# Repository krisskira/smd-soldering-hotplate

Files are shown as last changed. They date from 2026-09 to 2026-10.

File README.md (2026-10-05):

<a href="https://krisskira.github.io/smd-soldering-hotplate/">
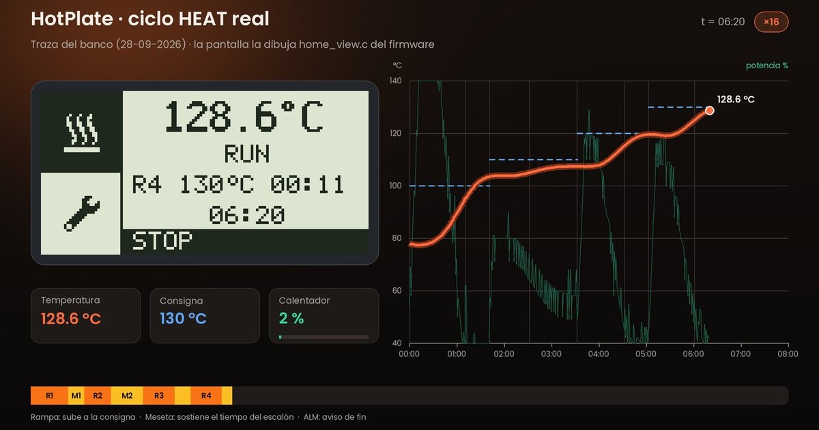
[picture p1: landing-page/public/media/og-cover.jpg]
HotPlate: a real HEAT cycle, with HotPanel and the temperature curve
  
</a>

# HotPlate

An open SMD reflow station. Instead of heating by eye, it runs a **Soldering Profile**: a precise temperature curve, step by step. It ramps under control, holds each plateau for the right time, signals when it is done and cools down on its own.

[Site](https://krisskira.github.io/smd-soldering-hotplate/) · [HotPanel and Studio](#two-ways-to-run-it) · [Docs](docs/README.md) · [Email](mailto:krisskira@gmail.com) · [Leer en español](README.es.md)

## What it does

- **HEAT** runs the whole profile from one gesture: optional wait, preheat, up to four rising or flat steps, then cooldown.
- **Scheduled start** waits from 00:00 (immediate) up to 12:00 before the cycle begins.
- **Predictive PI** cuts power before the target, so the plate's own inertia does not overshoot.
- **Autotune**, launched from HotPlate Studio, learns how the plate responds and stores the gains.
- **Safety** keeps the heater off at boot. A sensor fault or a reading above `temp_max_c` cuts the output at once.

## Two ways to run it

- **HotPanel**, the onboard interface: a large temperature, two tiles and a knob. Turn to choose, press to confirm. Heat starts or stops the cycle. Settings edits the four steps and the wait clock.
- **HotPlate Studio**, the desktop app over USB: live temperature chart, profile editing, CSV export, autotune and the limits the panel does not expose. When Studio takes control, HotPanel shows **USB** and local input locks. The two modes never run together.

## What's in the repo

- [`firmware/avr/`](firmware/avr/) — ATmega16 firmware at 8 MHz. The map of docs and code starts at [product features](firmware/avr/doc/product_features.md), [program flows](firmware/avr/doc/program_flows.md) and [architecture](firmware/avr/doc/architecture.md).
- [`hotplate-studio/`](hotplate-studio/) — HotPlate Studio (Python). The screens it follows are in [`hotplate-studio/design/`](hotplate-studio/design/).
- [`hardware/`](hardware/) — KiCad board and datasheets.
- [`mechanical/`](mechanical/) — 3D enclosure, covers and knob.
- [`landing-page/`](landing-page/) — the public site, React and TypeScript on Vite.

Flash is 16 KB. Thermal control, safety and the approved UI come first. See the [feature budget](firmware/avr/doc/feature_budget.md).

## Build

```bash
cd firmware/avr && make clean && make && make size && make usb-host-test

cd hotplate-studio && pip install -r requirements.txt && python app.py

cd landing-page && npm install && npm run dev
```

The site publishes to GitHub Pages from `.github/workflows/pages.yml` on every push to `main` that touches `landing-page/`. In the repository: **Settings → Pages → Source: GitHub Actions**.

## License

Open hardware and software. Use, study, modify and share it at your own risk. It works with mains power and high temperatures.

| What | License |
|---|---|
| Firmware and HotPlate Studio | [MIT](LICENSE) |
| Board and 3D models | [CERN-OHL-P-2.0](LICENSE) |
| Docs and icons | [CC BY 4.0](LICENSE) |

The full text is in [LICENSE](LICENSE).

Author: **Crhistian David Vergara Gómez** · **krisskira@gmail.com**

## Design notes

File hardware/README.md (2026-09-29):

# Hardware

## PCB (`pcb/`)

Proyecto KiCad de **HotPlate**:

- `controller.*` — placa de control (ATmega16, LCD, encoder, MAX31865, …)
- `power-stage.*` — etapa de potencia / SSR
- `smd-soldering-hotplate-pcb.csv` — BOM
- `pcb-cnc/` — exports CNC si aplica

Abrir los `.kicad_pro` con KiCad 8+.

## Datasheets (`datasheets/`)

PDFs de referencia: ATmega16, MAX31865, MOC3021, BT136, ST7920, CH340, HLK-PM01, etc.

Pines de firmware: `firmware/avr/doc/atmega16_pin_definition_hotplate.md` ↔ `firmware/avr/config/board_pins.h`.

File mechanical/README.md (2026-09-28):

# Mecánica / carcasa 3D

Modelos de carcasa, tapas y perilla (Fusion 360 / 3MF para impresión).

| Archivo | Notas |
|---|---|
| `Case.3mf` / `SolderingHotPlateCase.3mf` / `Hotplate.3mf` | Carcasa |
| `hotplate-INFERIOR.3mf` | Base inferior |
| `Hotplate-Tapa-trasera.*` | Tapa trasera (3MF + Fusion) |
| `tapa y perilla.f3d` | Tapa + perilla (Fusion) |
| `air-flower.3mf` | Difusor / aire |

Origen: exportados desde el diseño mecánico del producto (antes en `pcb/3D-Case`).

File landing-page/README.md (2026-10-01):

# Sitio de HotPlate

React, TypeScript y Vite. Se publica en
<https://krisskira.github.io/smd-soldering-hotplate/>.

```bash
npm install
npm run dev
npm run build
```

- Texto y secciones: `content/landing.json`
- Nombre, SEO y enlaces: `content/site.json`
- Traducción al inglés: `content/en.json` (la clave es el texto en español, exacto)
- Colores y fuentes: `content/theme.css`
- Imágenes y video: `public/media/`

## Publicar

El workflow `.github/workflows/pages.yml` construye y publica en GitHub Pages
cada push a `main` que toque `landing-page/`. En el repositorio:
**Settings → Pages → Source: GitHub Actions**.

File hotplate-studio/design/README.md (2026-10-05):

# Diseño de HotPlate Studio

Esta carpeta es la referencia visual de HotPlate Studio, la app de la carpeta de arriba ([`hotplate-studio/`](../)). El código sigue estas pantallas.

El detalle del cable (órdenes AT y tramas) está en [usb-automation.md](../../firmware/avr/doc/usb-automation.md). El orden del ciclo de soldadura, en [program_flows.md](../../firmware/avr/doc/program_flows.md).

## Qué hay en cada carpeta

| Carpeta | Qué es |
|---|---|
| [`stitch/`](stitch/README.md) | El diseño vigente. Cada pantalla tiene un PNG (cómo se ve) y un HTML (textos, jerarquía y colores) |
| `previews/` | Capturas de la app real con datos de demostración. Las usa la landing |
| `tools/` | `capture_previews.py` regenera `previews/`. `compare_stitch.py` pone la app al lado del PNG de Stitch |

Las capturas salen de la app de verdad: se abre en una ventana de 1280 px, se simula un equipo en modo USB y se guarda cada página completa. No toca tus `ramps.json`, `tune_params.json` ni `ui_theme.json`. Las curvas vienen de un modelo térmico sencillo (`tools/demo_data.py`), no de un equipo.

```mermaid
flowchart LR
  stitch[stitch/ · diseño] -->|se implementa en| app[views/ · la app]
  app -->|capture_previews.py| previews[previews/ · capturas]
  previews -->|prepare_media.py studio-| landing[landing-page · studio-*.webp]
  app -->|compare_stitch.py| cmp[app junto al PNG de Stitch]
  stitch --> cmp
```

Regenerar las capturas y pasarlas a la landing (desde la raíz del repo):

```bash
.venv/bin/python hotplate-studio/design/tools/capture_previews.py
cd landing-page && ../.venv/bin/python resources/prepare_media.py studio-
```

| Captura | Estado que muestra |
|---|---|
| `01_conexion.png` | En línea, modo USB, consola con el saludo y la lectura de ajustes |
| `02_heat_en_curso.png` | HEAT en la meseta de la rampa 4 |
| `03_heat_terminado.png` | HEAT terminado con el aviso de fin (`ALARM:2`) |
| `04_heat_falla.png` | Corte por falla de sensor (`FL=1`) en la subida de la rampa 2 |
| `05_autotune_listo.png` | Autoajuste terminado, 5 de 5 ciclos |
| `06_ajustes.png` | Ajustes leídos del equipo |
| `07_apariencia.png` | Apariencia · Fuentes |

## Las cinco pantallas

La cabecera no cambia de página. La barra de abajo tampoco: un punto de color, el puerto y el modo.

```mermaid
flowchart LR
  cabecera[Cabecera]
  cabecera --> conexion[Conexión]
  cabecera --> heat[HEAT]
  cabecera --> autotune[Autotune]
  cabecera --> ajustes[Ajustes]
  cabecera --> apariencia[Apariencia]
```

| Pantalla | Qué resuelve |
|---|---|
| Conexión | Abrir el puerto, pasar a USB y ver el tráfico |
| HEAT | Editar el perfil, lanzar el ciclo y ver la curva |
| Autotune | Hacer el ensayo y leer Kp y Ki |
| Ajustes | Límites, bandas de meseta, retraso, aire y ganancias. Se guardan en el equipo |
| Apariencia | Fuentes y colores. Solo en este computador |

HEAT y Autotune usan el mismo panel de estado y la misma curva. Cambian el formulario de arriba y el título de la gráfica.

## Tomar el control

```mermaid
flowchart TD
  off[Desconectado · punto rojo] -->|Conectar y AT con OK| manual[En línea · Manual]
  manual -->|Cambiar a modo USB| usb[En línea · USB]
  usb -->|Modo Manual, EXIT en el panel o reinicio| manual
  manual -->|Desconectar| off
  usb -->|Desconectar| off
```

En USB el panel del equipo solo muestra la temperatura, la palabra USB y un botón EXIT. Sin ese modo el equipo rechaza arrancar, parar o guardar (`ERROR:3`).

Al pasar a USB la app lee el perfil y los ajustes, y deja de preguntar el estado: el equipo lo envía solo, una vez por segundo.

## Un ciclo HEAT

El perfil tiene de 1 a 4 escalones seguidos, desde la rampa 1. Cada uno sube hasta su temperatura y luego sostiene la meseta. La temperatura no puede bajar de un escalón al siguiente. El retraso, si no es `00:00`, cuenta atrás sin calor.

```mermaid
flowchart TD
  start([Iniciar HEAT]) --> dly{¿Retraso mayor que 00:00?}
  dly -->|sí| espera[Espera · sin calor]
  dly -->|no| sube[Subida del escalón]
  espera --> sube
  sube --> banda{¿Temperatura dentro de la banda?}
  banda -->|no| sube
  banda -->|sí| meseta[Meseta]
  meseta --> mas{¿Quedan escalones?}
  mas -->|sí| sube
  mas -->|no| aviso[Aviso de fin]
  aviso --> frio{¿Aire activo y aún por encima del mínimo?}
  frio -->|sí| aire[Enfriando · aire]
  frio -->|no| listo([Terminado])
  aire --> listo
```

Parar el ciclo en espera, subida o meseta no corta en seco: el equipo lo trata como fin y sigue por el aviso y el enfriamiento. Un fallo de sensor, una sobretemperatura o una consigna que no se alcanza cortan la salida y la pantalla lo marca como falla.

El autoajuste es otro ensayo: oscila alrededor de una consigna, calcula Kp y Ki, y solo los guarda si termina bien.

## Decisiones que la interfaz respeta

- El idioma de la interfaz es español. Temperaturas en °C, mesetas en segundos, el retraso como reloj `hh:mm` (de `00:00` a `12:00`).
- La consigna no pasa de 250 °C ni de la temperatura máxima del equipo. La máxima puede llegar a 260 °C.
- La apariencia no se envía al HotPlate. El perfil, los límites y las ganancias sí.
- La ventana se abre maximizada y no se puede dejar por debajo de 1100×760.

## Colores de base

| Uso | Color |
|-----|---|
| Fondo | `#f4f6f8` |
| Tarjeta | `#ffffff` |
| Texto | `#2c3e50` |
| Texto secundario | `#5d6d7e` |
| Acento y botones principales | `#1a5276` |
| Temperatura medida | `#c0392b` |
| Consigna | `#2980b9` |
| Potencia | `#27ae60` |

La lista de pantallas, con su PNG y el archivo de código que la implementa, está en [stitch/README.md](stitch/README.md).

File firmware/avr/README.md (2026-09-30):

# SMI Soldering Hot Plate – Firmware AVR

Firmware ATmega16 @ **8 MHz**: HOME (Heat|Settings), HEAT (+ fase PREHEAT), PID_TUNE,
rampas EEPROM, PID (SSR MOC3021+BT136), MODO USB / AT, EEPROM **v8**.

**Docs:** [product_features.md](doc/product_features.md) (producto + mapa código) · [program_flows.md](doc/program_flows.md) · [architecture.md](doc/architecture.md) · [usb-automation.md](doc/usb-automation.md)

## Build

```bash
cd firmware/avr
make clean && make && make size
make usb-host-test
make flash
```

Presupuesto flash: **16384 B (100% típico)**. Tras cualquier cambio: `make size`.

## Características

- Home: Heat (temp 2×, fase, info) | Settings embebido (R1…R4 + DLY `hh:mm`, tope 12:00)
- Overlay USB: temp + `USB` + icono 16×16; solo entra con `AT+MODE=1`
- Programas AT: `AT+RUN=1` (HEAT), `AT+RUN=2` (PID_TUNE). PREHEAT **no** es programa
- Pipeline HEAT: retraso `00:00`…`12:00` (si no es cero) → rampa 1…n → aire @ `temp_min`
- El retraso se guarda como hora + minuto (2 bytes). La trama `DLY` sigue en segundos (`h×3600+m×60`, tope 43200)
- Safety: `temp_min` 50..100, `temp_max` 40..260 (EEPROM), consigna ≤ 250
- Pies LCD: `RUN` / `STOP` / `EXIT`

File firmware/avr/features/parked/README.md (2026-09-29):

# Features útiles, fuera del binario

Código que ya probamos y que no entra a `make`. La documentación sigue en
`firmware/avr/doc/`. Para volver a usarlo, hay que añadir el `.c` al Makefile.

## Animaciones ST7920

`st7920_animation.c` reproduce un GIF convertido a frame 0 + diffs
(`st7920_animation_run` / `run_all`). El super-loop de producto no lo llama.
Con `-ffunction-sections` el enlazador ya lo descartaba; sacarlo del driver
evita que una vista nueva lo arrastre sin querer.

El icono USB sigue en el binario (`st7920_write_frame_pgm`).

La vista de gráfico de `pid_atune` puede reutilizar este reproductor. Hasta
entonces no se enlaza: los frames de un chart en tiempo real ocuparían flash
y un buffer en RAM por animación activa.

Generador: `tools/gif_to_st7920_anim.py`. Guía: `doc/st7920_pantalla.md`.

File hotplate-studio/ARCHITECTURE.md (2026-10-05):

# Cómo está armada

La ventana solo dibuja. Cada botón pide una acción al controlador, el controlador habla con el equipo por el puerto serie, y la respuesta vuelve a pintarse en la vista.

```mermaid
flowchart LR
  vistas[Vistas] -->|acción| controlador
  controlador -->|una orden AT| serie[Puerto serie]
  serie -->|19200 8N1| equipo[HotPlate]
  equipo -->|OK, ERROR, $HP, $CF, $R| serie
  serie --> controlador
  controlador --> estado[Estado de sesión]
  estado --> vistas
```

Hay una sola orden en vuelo: se espera `OK` o `ERROR` antes de enviar la siguiente. Una trama `$HP` que llegue en medio no cuenta como esa respuesta.

Al conectar, la app envía `AT` y toma `OK` como «en línea». El saludo `HP` del equipo solo sale al encender, así que abrir el puerto no lo vuelve a ver.

## La sesión

```mermaid
flowchart TD
  off[Desconectado] -->|Conectar| wait[Preguntando al equipo]
  wait -->|AT y OK| manual[En línea · Manual]
  manual -->|AT+MODE=1| usb[En línea · USB]
  usb -->|AT+MODE=0, EXIT o reinicio| manual
  manual -->|Desconectar| off
  usb -->|Desconectar| off
```

En Manual la app puede preguntar el estado (`AT+STAT?`) cada cierto tiempo. En USB no lo hace: el equipo envía `$HP` solo, una vez por segundo. Al entrar en USB lee el perfil (`$R`) y los ajustes (`$CF`).

Salir de USB ocurre de tres maneras: el botón **Cambiar a modo Manual**, el botón EXIT del panel (`ERROR:8`) o un reinicio del equipo (llega otra vez el saludo `HP`).

## Pantallas

Cinco páginas, más una cabecera y una barra de estado que no cambian:

| Página | Archivo | Para qué |
|---|---|---|
| Conexión | `views/connection_view.py` | Puerto, modo Manual/USB, consola del tráfico |
| HEAT | `views/heat_view.py` | Perfil de hasta 4 escalones y el ciclo |
| Autotune | `views/tune_view.py` | Ensayo que calcula Kp y Ki |
| Ajustes | `views/settings_view.py` | Límites, bandas, retraso, aire y ganancias |
| Apariencia | `views/appearance_view.py` | Fuentes, colores de la gráfica y de la consola |

HEAT y Autotune comparten el panel de estado (`views/status_panel.py`) y la curva con su registro de eventos (`chart.py`). La apariencia no viaja al equipo.

Las cinco páginas están siempre montadas, una encima de otra y del tamaño de la ventana; cambiar de pestaña solo trae una al frente. Así las páginas que no se ven siguen midiendo lo mismo mientras reciben `$HP`. Si se desmontaran, los bloques que se reacomodan según el ancho (estado, HUD) entrarían en un bucle de relayout y congelarían la ventana.

Los nombres que se ven en pantalla (fases, errores, alarmas) salen de `protocol.py`. El orden real del ciclo lo decide el firmware; está en [program_flows.md](../firmware/avr/doc/program_flows.md).

## Archivos

| Archivo | Qué hace |
|---|---|
| `app.py` | Arranque |
| `window.py` | Ventana, páginas y el tamaño |
| `controller.py` | Órdenes, sondeo y reparto de las respuestas |
| `state.py` | Datos de la sesión, sin widgets |
| `protocol.py` | Arma las órdenes AT y lee las tramas |
| `serial_link.py` | Puerto a 19200 8N1 y el candado de una orden |
| `heat_logic.py` | Objetivo de temperatura del ciclo HEAT |
| `ramps_store.py`, `tune_store.py`, `theme.py` | Lectura y escritura de los tres JSON |
| `widgets/ui.py` | Botones, tarjetas y campos, dibujados a la medida del diseño |
| `build.sh` | Compila la app a un ejecutable |
| `design/` | Pantallas de Stitch, capturas de la app y las herramientas que las generan ([README](design/README.md)) |

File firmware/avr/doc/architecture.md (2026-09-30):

# Arquitectura del firmware AVR

Maestro de fases, alarmas y EEPROM: [program_flows.md](program_flows.md). Si este archivo discrepa, manda ese.  
Producto (+ mapa código): [product_features.md](product_features.md).
UI: [ui_style_guide.md](ui_style_guide.md). AT: [usb-automation.md](usb-automation.md).  
Flash / minify: [feature_budget.md](feature_budget.md) (skill `hotplate-feature-budget`).  
PI / Autotune: [pid_control.md](pid_control.md).  
Temporización (sin bloquear): [temporizacion_no_bloqueante.md](temporizacion_no_bloqueante.md).

Última revisión: 2026-09-29. Un solo binario (`make`). Sin perfiles PANEL/USB.

## Core vs shell

| Capa | Incluye | Regla |
|---|---|---|
| **Core** | `program_runner`, `pid`, `pid_atune`, `cfg_store`, `at_cmd`, `app_state`, sensor, safety, outputs, alarmas/beeps | Dueño del comportamiento térmico. En conflicto de flash, el core gana. |
| **Shell** | `home_view` (Heat + Ajustes embebido + overlay USB), ST7920, fonts, i18n | Adaptador: refleja `app_state_t`. No redefine la secuencia. |

Presupuesto de UI (iconos, animaciones, fuentes grandes): se decide con **`make size`** + [feature_budget.md](feature_budget.md), no con prohibiciones eternas. Mientras el margen sea mínimo, no se enlazan módulos parked (`features/parked/`). **UI aprobada** (iconos 16×16, temperatura 8×12) no se sacrifica para meter AT opcional.
## Actuador de calor

Banco PTC1+PTC2: GPIO → optoacoplador **MOC3021** → triac **BT136** (SSR). No es un relé mecánico. Ver BOM PCB y [program_flows.md](program_flows.md).

## Árbol

```
firmware/avr/
  src/main.c                 super-loop; g_state
  src/app/                   app_state.h, app_config.h (EEPROM v8)
  src/ui/                    home (Heat|Ajustes embebido|overlay USB)
  src/ui/core/               window, bands, texto
  src/services/program/      máquina de fases (HEAT con fase PREHEAT / PID_TUNE)
  src/services/pid*.c        lazo + autotune
  src/services/cfg_store.c   EEPROM global + heat/pre/tune + rampas
  src/services/at_cmd.c      AT
  lib/                       drivers + i18n
```

## Capas

```mermaid
flowchart TB
  main["main.c g_state"]
  shell["ui_router → home_view"]
  coreUi["ui/core"]
  svc["services program PID cfg AT safety"]
  lib["lib ST7920 MAX31865 UART ports"]
  main --> shell
  main --> svc
  shell --> coreUi
  shell --> svc
  svc --> lib
  coreUi --> lib
```

## Estado

Una `app_state_t` en `main.c`. Programas lanzables: `HEAT`, `PID_TUNE`. PREHEAT es fase de HEAT. **RAMPS** solo perfil EEPROM.

| Campo clave | Rol |
|---|-----|
| `program` / `phase` | Qué corre y en qué etapa |
| `delay_h` / `delay_m` | HEAT: 00:00 = inmediato; si no, PH_DELAY. Tope 12:00. Cuenta atrás en `dly_h/m` + `dly_s` (0…59) |
| `ramp_*` | Perfil de escalones |
| `temp_min_c` / `temp_max_c` | Safety + límites de consignas; aire OFF en min |
| `pid_k*` / `atune_*` | Lazo y autoajuste. Picos en RAM. Un `$HP` a 1 Hz en toda la sesión USB; `atune_stream` lo enriquece durante el autotune. Sin `$HP,PLOT` ni buffer de traza |
| `preheat_en` / `preheat_pct` | HEAT: saltar PREHEAT→STABILIZE, o tope en % de Ramp1 |
| `device_mode` | MANUAL vs USB |

## Navegación

```mermaid
flowchart LR
  home["HOME Heat Settings"]
  set["panel Ajustes en Home"]
  pid["PID via AT only"]
  run["HOME en marcha"]
  usb["overlay USB en Heat"]
  home -->|Heat PRESS| run
  home -->|Settings PRESS| set
  set -->|EXIT| home
  set --> pid
  run -->|STOP| home
  atUsb["AT MODE=1"] --> usb
  usb -->|EXIT| home
```

PREHEAT no es programa ni casilla de Home: es la fase de HEAT. UI Ajustes: header `SETUP`, 2 px de aire, R1…R4 + reloj **DLY** (`hh:mm`, tope 12:00); bandas de 9 px y 1 px de separación, 4 filas visibles con desplazamiento. Heat: temp 2×, fase, `Rx T°C` y tiempo, transcurrido `mm:ss`. Aire y PID solo AT.

## Super-loop

```mermaid
flowchart TD
  r[refresh UI] --> e[encoder]
  e --> a[AT]
  a --> s["1 Hz: sensor, muestra PID o atune, safety"]
  s --> p[process_tick]
  p --> t["telemetry si dirty"]
  t --> b[buzzer]
  b --> r
```

En ese tick de 1 Hz se arma el beep `READY` al entrar en `HOLD` o `DONE`, y en USB se marca la telemetría pendiente: sale un `$HP` por muestra ([usb-automation.md](usb-automation.md)). El UART va a 19200; cada trama bloquea 34–54 ms.

Detalle de fases: [program_flows.md](program_flows.md).

## Seguridad

- Boot, fault y sobretemperatura: PTC y fan OFF.
- `temp ≥ temp_max_c` (lectura válida) → UART **`ERROR:7`**, fase `PH_FAULT`, `$HP` `A=FAULT`. El corte (defecto 210 °C, rango 40…260) no es el techo de consigna (250 °C).
- Subida imposible: 180 s con duty ≥ 95 %, pendiente ≤ 0,2 °C/s y T bajo la banda → **`ERROR:9`**, calor OFF, `PH_FAULT`.
- Sensor inválido con programa activo (salvo DELAY/ALARM) → fault.

## Flash

Límite ATmega16: **16384 B**. Medir con `make size` tras cada cambio. Fuentes enlazadas: `FONT_5X7`, `FONT_8X12` (temperatura con `°C`), `FONT_5X7_X2` (misma tabla a 2×, título USB) y `FONT_ICONS` (Heat/CFG).

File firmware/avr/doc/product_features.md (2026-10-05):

# Características del producto — SMI Soldering Hot Plate

Este documento describe **qué hace HotPlate y cómo se comporta**, desde el punto de vista del producto: qué programas tiene, cómo avanza un ciclo de soldadura, qué muestra HotPanel, qué se puede configurar y dónde se guarda.

Firmware en `firmware/avr/`, microcontrolador ATmega16 a 8 MHz. Última actualización: 2026-09-29.

**Documentos relacionados**

| Documento | Cuándo consultarlo |
|---|---|
| [program_flows.md](program_flows.md) | Fases, alarmas y EEPROM. **Si hay contradicción térmica con este documento, manda ese.** |
| [architecture.md](architecture.md) | Capas, módulos y super-loop |
| [usb-automation.md](usb-automation.md) | Comandos AT y tramas `$HP` / `$CF` / `$R` |
| [pid_control.md](pid_control.md) | Lazo PI predictivo y autoajuste |
| [ui_style_guide.md](ui_style_guide.md) | Layout, tipografía e iconos de HotPanel |
| [feature_budget.md](feature_budget.md) | Flash por feature y qué se puede recortar |
| [temporizacion_no_bloqueante.md](temporizacion_no_bloqueante.md) | Reloj `avr_delay` sin bloquear |
| [st7920_pantalla.md](st7920_pantalla.md) | Bitmaps, diffs y animaciones LCD |
| [atmega16_pin_definition_hotplate.md](atmega16_pin_definition_hotplate.md) | Pines MCU (vs `config/board_pins.h`) |
| [mejoras_futuras.md](mejoras_futuras.md) | Erratas térmicas y algoritmo pendiente. **No es el comportamiento actual.** |

Si este archivo discrepa del **código**, manda el código y hay que corregir el documento.

---

## 1. Visión general

**HotPlate** ejecuta un **Soldering Profile**: sube la temperatura de forma controlada, la mantiene en cada escalón el tiempo indicado y, al terminar, apaga el calefactor y avisa. Se puede operar de dos maneras, **nunca a la vez**:

- **Modo manual**: desde **HotPanel**, la interfaz a bordo de HotPlate.
- **Modo USB**: desde un PC mediante comandos AT por UART (normalmente con *HotPlate Studio*, en `hotplate-studio/`). Mientras este modo está activo, HotPanel queda bloqueado.

### Hardware implicado

| Función | Componente | Comentario |
|---|---|---|
| Medición de temperatura | PT100 + MAX31865 | Lectura cada 1 s |
| Calefacción | Dos resistencias PTC (PTC1 + PTC2) accionadas por MOC3021 + BT136 | Relé de estado sólido (SSR); no hay relé mecánico |
| Enfriamiento | Bomba de aire / ventilador | Solo al final del ciclo o durante el autotune |
| Avisos | Buzzer piezoeléctrico | Pitidos de proceso |
| Pantalla ST7920 128×64 | Display de **HotPanel** | Interfaz a bordo |

---

## 2. Programas

El firmware tiene **dos programas ejecutables** y el **Soldering Profile** (datos de escalones):

| Programa | Qué hace | Se lanza desde |
|---|---|---|
| **HEAT** | Ciclo completo de soldadura según el Soldering Profile | HotPanel (casilla Heat) o USB (`AT+RUN=1`) |
| **PID_TUNE** | Autoajuste de las ganancias del control | Solo USB (`AT+RUN=2`) |
| **RAMPS** | *No es un programa*: es el Soldering Profile (hasta 4 escalones) que HEAT recorre. Se guarda en EEPROM y se edita con `AT+CFG=R` o desde Ajustes | — |

> La rampa 1 es el primer escalón del perfil. No hay una fase previa al porcentaje de esa rampa.

### 2.1 HEAT — ciclo de soldadura

Un ciclo HEAT recorre estas fases en orden:

| # | Fase | Qué ocurre | Calefactor | Ventilador | Cuándo avanza |
|---|---|---|---|---|---|
| 1 | **Espera** (`WAIT`) | Cuenta atrás antes de empezar. Se omite si el retraso es `00:00` | OFF | OFF | Al llegar a 0 |
| 2 | **Rampa i – subida** (`RUN`) | Sube hacia la temperatura del escalón i (la rampa 1 es el primer escalón). El tiempo **todavía no corre** | PI | OFF | Al entrar en ±`BN` °C del objetivo |
| 3 | **Rampa i – meseta** (`HOLD`) | Mantiene la temperatura del escalón durante su `hold_s` | PI | OFF | Al agotarse `hold_s`: siguiente rampa o fin |
| 4 | **Fin** (`ALM`) | Calefactor apagado, pitidos de aviso y `ALARM:2` por USB | OFF | ON si `cooldown_air_en` | Tras 60 s o al confirmar el usuario |
| 5 | **Enfriamiento** (`AIR`) | Solo si el aire asistido está activado. Sopla hasta bajar a `temp_min_c` | OFF | ON | `T ≤ temp_min_c` |
| 6 | **Terminado** (`END`) | Todo apagado | OFF | OFF | — |

**Detalles importantes del comportamiento**

- **Entrar en meseta.** La subida pasa a meseta al estar a ±`BN` (4 °C por defecto) del objetivo. La meseta no se aborta si la temperatura se sale; corre su `hold_s`.
- **Perfiles.** RSS, rampa a pico, reflow o soldadura son el mismo HEAT con distinto Soldering Profile: la rampa 1 es el primer soak y las siguientes, si las hay, suben o se mantienen.
- **Rampas solo ascendentes.** Se admiten hasta 4 escalones y cada uno debe tener una temperatura igual o mayor que el anterior. Un Soldering Profile descendente se rechaza con `ERROR:2`.
- **El aire solo actúa al final.** El ventilador nunca se enciende entre rampas; solo en la fase de enfriamiento, y solo si `cooldown_air_en` está activado.

**Cancelar un ciclo**

| Cómo se cancela | Resultado |
|---|---|
| Desde HotPanel (Cancelar) en espera o rampas | Parada inmediata → `IDLE`. No se emite `ALARM:2` |
| Con `AT+STOP` por USB en esas mismas fases | Se trata como un fin de ciclo → fase de fin + `ALARM:2` |
| Confirmación (HotPanel o `AT+STOP`) durante la fase de fin | Cierra la alarma y pasa a enfriamiento o a terminado |

### 2.2 PID_TUNE — autoajuste

Calcula automáticamente las ganancias del control de temperatura. **Solo se lanza por USB**; HotPanel no ofrece esta opción.

- **Lanzamiento:** `AT+RUN=2,temp,ciclos,hyst[,max_s]`. Los parámetros se pueden guardar antes, sin arrancar, con `AT+CFG=T`.
- **Funcionamiento:** el calefactor se enciende y apaga por completo (control todo/nada) alrededor de la temperatura objetivo, con una histéresis de ±1,5 °C por defecto. Durante los tramos con el calefactor apagado se enciende el ventilador para acortar la bajada y limitar el tiempo que los componentes pasan por encima de la consigna.
- **Resultado:** tras el número de ciclos indicado (5 por defecto, rango 3–10), el firmware mide la amplitud y el periodo de la oscilación y calcula Kp y Ki por el método de Ziegler–Nichols (variante PI, Kd = 0).
- **Guardado:** al terminar, Kp y Ki se escriben solos en EEPROM. No hay `AT+CFG=A`.
- **Límite de tiempo:** si el proceso supera `atune_max_s` (2000 s por defecto, rango 120–3600 s), se aborta con fallo.
- **Telemetría:** en USB el equipo envía un `$HP` por segundo. Mientras dura el autoajuste esa misma trama suma el progreso (`AP`, `AC`) y las ganancias (`AK`, `AI`). Ver [usb-automation.md](usb-automation.md).

Detalle matemático: [pid_control.md](pid_control.md).

---

## 3. Control de temperatura

Durante el precalentamiento, la estabilización y las rampas, la potencia del calefactor la decide un **lazo PI predictivo**:

- **Referencia progresiva.** En lugar de pedir la temperatura final de golpe, el control persigue una referencia interna (`t_ref`) que sube a un ritmo limitado hacia la consigna (1,2 °C/s, constante `RISE_C_X10_DEFAULT`). Así la subida es suave y controlada.
- **Anticipación de la inercia.** El error se calcula con la temperatura que *habrá* dentro de unos segundos (temperatura actual + velocidad de subida × 15 s, constante `LOOKAHEAD_S_DEFAULT`). Esto permite cortar potencia antes de llegar a la consigna y evitar el sobrepaso típico de HotPlate por su masa térmica.
- **Sin término derivativo.** Solo se usan Kp y Ki (Kd = 0). Valores por defecto: Kp = 24,6 y Ki = 0,10/s (Kp ×10 = 246; Ki ×100 = 10).
- **Aplicación al SSR.** La salida del PI es un porcentaje que se aplica como tiempo de encendido dentro de una ventana de 1,5 s (control por proporción de tiempo).
- **Anti-windup.** Si la salida ya está saturada (0 % o 100 %) en la dirección del error, el integrador deja de acumular.
- **Cambio de escalón.** Al pasar a una nueva rampa, la referencia se alinea con la temperatura actual para que la subida arranque limpia, sin arrastrar el estado del tramo anterior.

Las constantes de subida y anticipación están fijadas en compilación (`app_config.h`) y no se guardan en EEPROM, para ahorrar flash.

---

## 4. Seguridad

- **Salidas apagadas por defecto.** Al arrancar el equipo, ante un fallo del sensor o por sobretemperatura, calefactor y ventilador quedan en OFF.
- **Sobretemperatura.** Si una lectura válida alcanza `temp_max_c`, se cortan ambas resistencias, la fase pasa a `FAULT` y por USB se emite `ERROR:7`. No hay pitido en este caso.
- **Límites configurables.**

| Parámetro | Función | Rango | Por defecto |
|---|---|---|---|
| `temp_min_c` | Temperatura mínima de cualquier consigna, y temperatura a la que se detiene el aire de enfriamiento | 50–100 °C | 50 °C |
| `temp_max_c` | Corte de seguridad; por encima se apaga la calefacción. No es el techo de las consignas (ese es 250 °C) | 40–260 °C | 210 °C |

Se ajustan por USB con `AT+CFG=S`.

---

## 5. HotPanel (interfaz a bordo)

**HotPanel** es la interfaz de HotPlate: una única vista **Home** con dos casillas laterales — **Heat** y **Settings**. No existen pantallas separadas para USB ni para ajustes; ambos se muestran dentro de Home.

### Casilla Heat

- Temperatura actual centrada a 2× (p. ej. `123.4°C`). Si el sensor no es válido, `ERR`.
- Fase actual.
- Rampa, consigna con `°C` y tiempo de esa etapa (`R2 180°C 01:30`). En reposo y en la espera ese tiempo es el reloj `hh:mm` (tope 12:00). En la meseta es `mm:ss`.
- Línea centrada con el tiempo desde el arranque, en `mm:ss` (`00:00` en reposo). Pasados 99 min se ve `100:00`.
- En el pie, **`RUN`** para arrancar el ciclo o **`STOP`** para cancelarlo.

### Modo USB

Cuando el PC toma el control (`AT+MODE=1`), la casilla Heat muestra la temperatura con la etiqueta **`USB`** a 2× y el pie cambia a **`EXIT`**, que permite recuperar el control manual. No se muestran la fase, el perfil ni el transcurrido.

### Casilla Settings

- Cabecera **`SETUP`** en vídeo inverso, con 2 px de aire debajo. El resaltado de cada opción deja 1 px por encima y por debajo de la letra, y 1 px sin invertir la separa de la siguiente. Se ven cuatro opciones; en DLY la lista sube una fila.
- Lista con las cuatro rampas (**R1…R4**) y el retraso (**`DLY`**): nombre a la izquierda, valor a la derecha. La meseta se muestra en segundos; el retraso, en `hh:mm`.
- Girar hasta la casilla ya enseña la lista. Pulsar entra a editarla; **`EXIT`** vuelve a Heat.

| Fila | Qué se ajusta |
|---|---|
| R1…R4 | Temperatura (pasos de 5 °C, entre `temp_min_c` y el techo de consigna, 250 °C o `temp_max_c` si es menor) y meseta (pasos de 30 s, de 30 s a 60 min). R2…R4 se apagan bajando de `temp_min_c` y confirmando con otra pulsación; R1 no se puede apagar |
| `DLY` | Retraso antes de empezar el ciclo, en `hh:mm`, desde `00:00` (inmediato) hasta `12:00`. Pulsar alterna horas y minutos |

### Etiquetas en HotPanel

Todas en inglés y mayúsculas, a través del sistema de traducción (i18n):

| Etiqueta | Significado |
|---|---|
| `IDLE` / `WAIT` | Reposo / cuenta atrás |
| `PRE` / `STAB` | Precalentamiento / estabilización |
| `RUN` | Subida o meseta; también el botón de arranque |
| `ALM` / `AIR` | Aviso de fin / enfriamiento |
| `END` / `ERR` | Terminado / fallo (sensor o sobretemperatura) |
| `STOP` / `EXIT` | Cancelar / salir |
| `OFF` | Rampa apagada, o perfil vacío |
| `DLY` / `USB` / `SETUP` | Fila de retraso, modo USB y cabecera de ajustes |

La lista completa, con el comportamiento de cada modo, está en [ui_style_guide.md](ui_style_guide.md).

---

## 6. Dónde se configura cada cosa

**HotPanel** solo expone lo necesario para el uso diario. El resto se configura por USB (comandos AT o HotPlate Studio).

| Ajuste | HotPanel | USB / HotPlate Studio |
|---|:---:|:---:|
| Rampas R1…R4 (temperatura y meseta) | ✔ | ✔ |
| Retraso de inicio (`delay_h` + `delay_m`) | ✔ | ✔ |
| Límites `temp_min_c` / `temp_max_c` | — | ✔ |
| Precalentamiento: activado, %, tiempo de estabilización, bandas | — | ✔ |
| Aire en el enfriamiento (`cooldown_air_en`) | — | ✔ |
| Ganancias PI | — | ✔ |
| Autotune (lanzar y parámetros) | — | ✔ |

> El zumbador solo pita en dos casos: la alarma de proceso (fin de ciclo, arranque rechazado) y un pulso corto cuando HotPanel guarda un valor en EEPROM. No hay pitido al mover el cursor, arrancar, parar ni salir de USB. Ver [feature_budget.md](feature_budget.md).

---

## 7. Avisos y alarmas

| Evento | Por USB | Pitido | Estado en `$HP` (`A=`) |
|---|---|---|---|
| Fin del ciclo HEAT | `ALARM:2` | 3 pulsos (50 ms ON / 80 ms OFF), repetidos cada 5 s mientras dura el aviso | `ALARM` |
| Sobretemperatura | `ERROR:7` | Ninguno | `FAULT` |
| Consigna inalcanzable | `ERROR:9` | Ninguno | `FAULT` |
| Llegada a una meseta o fin | — | 3 pulsos cortos | Fase nueva |
| Cambio de fase | No hay línea propia | Según la fase | Nombre de la fase nueva |

El estado del proceso se informa siempre dentro de la trama `$HP`, en el campo `A=`; no se envían líneas de alarma adicionales salvo `ALARM:n` y `ERROR:n`. Lista completa y reglas de pitidos: [program_flows.md](program_flows.md).

---

## 8. Datos guardados en EEPROM

La configuración se guarda en EEPROM (versión de formato **v8**). Si al arrancar la versión guardada no coincide con la del firmware, se cargan los valores por defecto (no hay migración).

| Dato | Por defecto | Notas |
|---|---|---|
| Ganancias Kp ×10 / Ki ×100 | 246 / 10 | El autotune las escribe al terminar, o `AT+CFG=P` |
| `temp_min_c` / `temp_max_c` | 50 / 210 °C | Corte de seguridad. Las consignas no pasan de 250 °C |
| `preheat_en` / `preheat_pct` | activado / 80 % | Rango del % : 50–100, pasos de 5 |
| `preheat_band_c` / `preheat_band_exit_c` | ±4 / ±6 °C | Bandas de entrada y salida de la estabilización |
| `atune_cycles_target` | 5 | Ciclos del autotune |
| `atune_hyst_c_x10` | 15 (±1,5 °C) | Histéresis del autotune |
| `atune_max_s` | 2000 s | Tiempo máximo del autotune |
| `stabilize_s` | 30 s | Duración de la estabilización |
| `cooldown_air_en` | activado | Aire en el enfriamiento final |
| Duración / periodo del aviso de fin | 60 s / 5 s | Tiempo total del aviso y cada cuánto se repite el pitido |
| `ee_heat` | — | Retraso de inicio de HEAT |
| `ee_tune` | — | Temperatura objetivo del autotune |
| `ee_ramp` | — | Soldering Profile: hasta 4 rampas (temperatura + meseta) |

No se guardan en EEPROM (son constantes de compilación en `app_config.h`): la velocidad de subida de la referencia (`RISE_C_X10_DEFAULT`) y el horizonte de anticipación (`LOOKAHEAD_S_DEFAULT`).

---

## 9. Núcleo y capa de presentación

El firmware separa dos niveles:

- **Núcleo (core):** HEAT, precalentamiento, control PI y autotune, Soldering Profile, estado central, alarmas y protocolo AT. Es la lógica que decide qué hace HotPlate.
- **Presentación (shell):** la vista Home, el aviso USB, el dibujo en LCD y los textos. Solo muestra el estado y recoge órdenes; **nunca cambia la secuencia del ciclo**.

Esta separación permite modificar la interfaz sin riesgo para el comportamiento térmico. Cuando falta flash, el núcleo y la interfaz aprobada tienen prioridad sobre funciones AT opcionales ([feature_budget.md](feature_budget.md)).

---

## 10. Compilación

La flash del ATmega16 es de **16 384 bytes**, así que el tamaño debe medirse en cada cambio:

```bash
cd firmware/avr && make clean && make && make size && make usb-host-test
```

Tras tocar tamaño/UI: skill **hotplate-feature-budget** y actualizar [feature_budget.md](feature_budget.md).

---

## 11. Mapa de código (dónde está cada cosa)

### Aplicación

```
src/main.c                      super-loop; g_state
src/app/app_config.h            constantes, HOME_DIRTY_*, EEPROM v8
src/app/app_state.h             app_state_t, fases, PROG_HEAT / PROG_PID_TUNE
src/ui/ui_router.c              → home_view
src/ui/home_view.c              Heat + Settings embebido + overlay USB
src/ui/core/ui_components.c     footer 5×7
src/ui/core/ui_text.c           helpers temp / mm:ss / hh:mm
src/services/program/           program_runner — fases HEAT (con PREHEAT)
src/services/pid.c / pid_atune.c
src/services/cfg_store.c        EEPROM global + heat + rampas
src/services/safety.c           corte → ERROR:7 (temp_max_c)
src/services/device_session.c   MANUAL / USB
src/services/at_cmd.c / telemetry.c
```

`ui_display.c` / `ui_window.c`: presentes en el árbol, **no** enlazados en el Makefile.

### Drivers (`lib/`)

| Módulo | Rol |
|---|-----|
| `avr_delay` | Timer0 → `delay_ms` / `_sec` / `_min` |
| `avr_spi` / `avr_soft_spi` | ST7920 / MAX31865 |
| `st7920` | LCD 128×64, bandas GDRAM |
| `max31865` | PT100 |
| `encoder` | Polling (CW = cursor baja) |
| `ports` | PTC, fan, buzzer |
| `avr_uart` | 19200 8N1 (igual en HotPlate Studio). TX bloqueante; anillo RX 32 B |
| `fonts` | 5×7; temperatura en 8×12 nativa (con `°C`); `USB` en 5×7 a 2×; ICONS 16×16 (ver budget) |
| `i18n` | PROGMEM CAPS inglés abreviado |

### Hechos cerrados

| Tema | Valor |
|---|---|
| PTC1 / PTC2 | `board_pins.h`: PD7 / PD6 |
| Encoder | CW = cursor baja |
| Reloj | `F_CPU` **8 MHz** |
| Programas AT | Solo HEAT (`RUN=1`) y PID_TUNE (`RUN=2`); PREHEAT es fase |
| RAMPS | Bloque EEPROM; no lanzable |
| Flash | 16384 B; medir con `make size` |

### Límites conocidos

- Sin vista aparte de alarma (`PH_ALARM` se muestra en Home / overlay USB).
- HotPanel Settings: header `SETUP`, 2 px de aire, R1…R4 + reloj DLY `00:00`…`12:00` (bandas de 9 px + 1 px de separación, 4 visibles con desplazamiento). Heat añade el transcurrido `mm:ss`. PID / aire / autotune solo AT / Studio.
- Sesión USB: un `$HP` a 1 Hz (reposo, HEAT y autotune enriquecido); picos en `pid_atune` (no en `app_state`); sin `$HP,PLOT`.
- Sin guía eléctrica aparte del KiCad + datasheets en `hardware/`.

### Skills / agentes

Ver [AGENTS.md](../../../AGENTS.md) en la raíz del monorepo.

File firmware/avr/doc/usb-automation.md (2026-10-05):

# UART / AT — HotPlate Studio ↔ HotPlate

Contrato de lo que entra y sale por el cable USB/serie.  
HotPlate Studio habla este protocolo; el firmware lo implementa en `at_cmd.c` + `telemetry.c`.

| Si hay duda sobre… | Mira |
|---|---|
| Fases, alarmas, EEPROM, pitidos | [program_flows.md](program_flows.md) (**manda** en el proceso térmico) |
| PI / autoajuste | [pid_control.md](pid_control.md) |
| Flash / qué se puede recortar | [feature_budget.md](feature_budget.md) |

---

## Cómo hablar con HotPlate

| Detalle | Valor |
|---|---|
| Puerto | UART **19200 8N1** (firmware y HotPlate Studio). Un cliente a 9600 no entiende la sesión |
| Forma | Una línea = un comando |
| Fin de línea | `\r` o `\n` |
| Mayúsculas | Sí |
| Espacios finales | Se ignoran |
| Largo máximo | **31** caracteres; si se pasa, la línea se descarta |

Al encender, HotPlate saluda una vez: `\r\nHP\r\n`. Abrir el puerto no reinicia el equipo, así que si ya estaba en marcha ese saludo ya pasó. HotPlate Studio, al conectar, envía `AT` y toma `OK` como «en línea». `HP` sigue valiendo si se enciende con el puerto abierto.

**Números, no nombres largos.** `ERROR:`, `ALARM:` y los campos `P` / `A` de `$HP` van como enteros. Los nombres de las tablas de abajo son solo para humanos (ahorro de Flash en el micro).

Hay **cinco verbos**: `MODE`, `RUN`, `STOP`, `CFG`, `STAT`.  
La rampa 1 es el primer escalón de HEAT: no es un programa AT ni una fase al % de esa rampa.

---

## Sesión: Manual vs USB

HotPanel (modo manual) y HotPlate Studio (modo USB) **no** mandan a la vez. Para tomar el control por USB el equipo tiene que estar libre.

| Comando | ¿Hace falta estar en USB? | Qué ocurre |
|---|---|---|
| `AT` | No | Ping → `OK` |
| `AT+MODE=1` | No | Entra en USB si está libre → `$HP` + `OK`. Ocupado → `ERROR:4`. Ya en USB → `OK` |
| `AT+MODE=0` | No | Vuelve a Manual (para la sesión), quita el overlay USB de HotPanel → `$HP` + `OK` |

`AT+STAT?` funciona sin estar en USB.  
El resto (`CFG`, `CFG?`, `RUN`, `STOP`) exige USB → si no, `ERROR:3`.

Con `AT+MODE=1`, HotPanel muestra en Heat la temperatura y la etiqueta **`USB`** a 2×, y el pie **`EXIT`**. No pinta la fase, el perfil ni el transcurrido.  
Pulsar **EXIT** en HotPanel: vuelve a Manual, emite `ERROR:8` y un pitido de confirmación ×2.

---

## Errores (`ERROR:n`)

Formato: `ERROR:<n>\r\n`

| n | Nombre (doc) | Cuándo |
|--:|---|---|
| 1 | INVALID_COMMAND | Comando desconocido / mal formado en USB |
| 2 | INVALID_PARAMETER | Argumento fuera de rango; `RUN=1` sin rampas; `RUN=2` inválido; `CFG=A` ya no existe |
| 3 | USB_MODE_REQUIRED | Comando que exige USB estando en Manual |
| 4 | DEVICE_BUSY | `MODE=1` con el equipo ocupado; `RUN` en fallo (`PH_FAULT`) |
| 5 | PROGRAM_BUSY | `RUN` con un ciclo o autoajuste ya en marcha |
| 6 | SENSOR_INVALID | `RUN` sin sensor válido |
| 7 | OVER_TEMPERATURE | Corte de seguridad (`temp_max_c`) |
| 8 | ABORTED_BY_DEVICE | Pulsar **EXIT** en el overlay USB de HotPanel |
| 9 | UNREACHABLE_SETPOINT | `PH_RUN`: 3 min con duty ≥ 95 %, pendiente ≤ 0,2 °C/s y T por debajo de la banda. Calor OFF, fase `FAULT`. No es el corte de `temp_max_c` |

---

## Alarmas (`ALARM:n`)

Líneas espontáneas mientras hay sesión USB: `ALARM:<n>\r\n`

| n | Nombre | Cuándo |
|--:|---|---|
| 2 | DONE | HEAT terminó las rampas (o `AT+STOP` en marcha, que cierra como fin). Cancelar desde HotPanel → IDLE **sin** `ALARM` |

No existe `ALARM:1`. El precalentamiento no emite alarma: al estabilizar (o al vencer el timeout de sobrepaso) pasa a la rampa.

---

## Programa y fase en `$HP`

`P=<n>` = qué programa corre:

| n | Programa |
|--:|---|
| 1 | HEAT (Soldering Profile) |
| 2 | PID_TUNE (autoajuste) |

`P=0` no existe.

`A=<n>` = fase del proceso (salvo autoajuste, que fuerza `A=10`):

| n | Fase | En palabras |
|--:|---|---|
| 0 | IDLE | En reposo |
| 1 | DELAY | Espera antes de calentar |
| 2 | — | Reservado. Ya no se emite (antes: precalentado al % de la rampa 1) |
| 3 | — | Reservado. Ya no se emite (antes: estabilización de ese %) |
| 4 | HOLD | Meseta del escalón |
| 5 | RUN | Subida hacia el SET |
| 6 | COOLDOWN | Enfriamiento con aire |
| 7 | ALARM | Aviso de fin |
| 8 | DONE | Listo |
| 9 | FAULT | Fallo / sobretemperatura |
| 10 | TUNING | Autoajuste en curso |

---

## Catálogo de comandos

| Comando | USB | Efecto | Se guarda | Respuesta OK |
|---|-----|---|---|---|
| `AT` | no | Ping | — | `OK` |
| `AT+STAT?` | no | Foto del proceso | — | `$HP` + `OK` |
| `AT+MODE=0\|1` | no | Manual / USB | — | `$HP` + `OK` |
| `AT+RUN=1` | sí | Arranca HEAT | — | `OK` / `ERROR:n` |
| `AT+RUN=2,<°C>,<ciclos>,<hyst>[,<max_s>]` | sí | Arranca autoajuste + stream | global + `ee_tune` | `OK` / `ERROR:n` |
| `AT+STOP` | sí | Parada | — | **solo `OK`** (sin `$HP`) |
| `AT+CFG=S,<min>,<max>` | sí | Límites de temperatura | global | `OK` |
| `AT+CFG=H,<delay>,<air>` | sí | Retraso (`00:00`…`12:00`, en segundos) y aire de HEAT | global + `ee_heat` | `OK` |
| `AT+CFG=B,<bn>,<bx>` | sí | Bandas ±°C (entrada / salida) | global | `OK` |
| `AT+CFG=P,<kp>,<ki>` | sí | Ganancias PI: Kp ×10, Ki ×100 (0…999) | global | `OK` |
| `AT+CFG=T,<ciclos>,<hyst>,<max_s>` | sí | Params autoajuste **sin** arrancar | global | `OK` |
| `AT+CFG=R,<i>,<°C>,<s>` | sí | Escalón 0…3 del Soldering Profile | `ee_ramp` | `OK` |
| `AT+CFG=R?` | sí | Lee escalones | — | `$R` + `OK` |
| `AT+CFG?` | sí | Lee ajustes | — | `$CF` + `OK` |

### Detalles de `CFG`

**`CFG=H`** — retraso y aire de HEAT  
`air` = 0 o 1 · `delay` 0…43200 s (`0` = inmediato, tope 12 h). Dos argumentos. El equipo guarda solo horas y minutos (el resto menor de 60 s se descarta). El antiguo `en,pct,stab` (precalentado al % de la rampa 1) ya no existe: la rampa 1 es el primer escalón, a su propia temperatura. Un argumento de más da `ERROR:2`.

**`CFG=P`** — ganancias PI  
`kp` ×10 / `ki` ×100 (0…999). Dos argumentos: el lazo no tiene término D, y un tercer valor (antiguo `kd`) da `ERROR:2`.

**`CFG=B`** — histéresis de bandas  
`bn` entrada ±°C (1…15): al entrar en esa banda, la subida de cualquier rampa pasa a meseta. `bx` se guarda (`bn`…20) y ya no aborta la meseta.

**`CFG=S`** — límites  
min 30…100 · max 40…260 · min ≤ max.

**`CFG=R`** — Soldering Profile
°C dentro de min…**techo de consigna**. El techo es `min(temp_max_c, 250)`. `temp_max_c` (defecto **210**, rango 40…260) es solo el corte de seguridad. Un escalón por encima del techo da `ERROR:2`. Hold 1…3600. Escribir el escalón `i` **fija** `ramp_n = i+1` y limpia los huecos altos (así se puede achicar N).
`temp=0` con `i≥1` deshabilita desde ese índice.  
Al `AT+RUN=1` el perfil debe ser **no decreciente** y cada escalón ≤ techo → si no, `ERROR:2`.
Lectura: `CFG=R?` → `$R`.

**`CFG=T` / `RUN=2`** — autoajuste
Consigna en **120…150 °C** y además dentro de `[Tmin .. Tmax−10]` · ciclos 3…10 · histéresis ×10 de 1…99 · `max_s` opcional 120…3600 (default EEPROM `AMS`, 2000 s).
`CFG=T` solo guarda; `RUN=2` arranca. Si un semiperiodo ON es ≥ 3× el OFF anterior, o la subida se aplana 180 s sin cruzar el umbral alto, termina en fallo y no escribe Kp/Ki.

---

## Lectura — proceso `$HP`

Foto del proceso. **No** lleva settings. En USB sale sola cada 1 s (stream de sesión). También sale con `STAT?`, `MODE` y cambios de fase, en los dos modos.

```
$HP,T=<°C.d|--->,P=<prog>,A=<action>,SET=<°C>,DLY=<s 0..43200>,RUN=<s>,EL=<s>,
DU=<0..100>,F=0|1,RI=<ramp_idx>,FL=0|1
```

Con stream de autoajuste se añade:

```
,AP=<fase>,AC=<ciclos hechos>,AK=<kp>,AI=<ki>
```

| Campo | Significado |
|---|---|
| `T` | Temperatura (°C con décima) o `---` si el sensor no vale |
| `P` `A` | Programa / fase (tablas de arriba) |
| `SET` | Consigna actual (°C) |
| `DLY` | Retraso configurado, en segundos de reloj (`h×3600+m×60`, tope 43200 = 12:00) |
| `RUN` | Tiempo restante de la fase (s) |
| `EL` | Tiempo transcurrido (s) |
| `DU` | Duty del banco PTC (0…100 %) |
| `F` | Ventilador 0/1 |
| `RI` | Índice del escalón en curso (`ramp_idx`). El contenido del perfil va en `$R` |
| `FL` | Fault 0/1 |
| `AP` | Fase del autoajuste: 0 IDLE, 1 RUN, 2 DONE, 3 FAIL |
| `AC` | Ciclos ya cerrados |
| `AK` `AI` | Kp ×10 / Ki ×100 del autoajuste (cero hasta DONE) |

`AK` / `AI` viven en el autoajuste, no en `app_state`. HotPlate Studio los grafica desde la trama.  
**Nota:** `AD` (Kd) **ya no se emite** (siempre 0; ahorro de Flash).

---

## Lectura — ajustes `$CF`

Solo con `AT+CFG?` (no a 1 Hz).

```
$CF,MN=<Tmin>,MX=<Tmax>,KP=,KI=,BN=<band_c>,BX=<band_exit_c>,DLY=<s>,AIR=0|1,AMS=<max_s>
```

| Campo | Significado |
|---|---|
| `MN` `MX` | Límites de temperatura |
| `KP` `KI` | Ganancias PI ×10. El autotune las escribe solo al terminar |
| `BN` `BX` | Banda para entrar en la meseta de una rampa (±°C). `BX` se guarda; la meseta no se aborta |
| `DLY` | Retraso de arranque en segundos de reloj (mismo criterio que `$HP`) |
| `AIR` | Aire al final de HEAT |
| `AMS` | Timeout global del autoajuste (s) |

No existen `KD` ni `SND` (el firmware ya no guarda Kd ni el flag de sonido). `RN` se omite por Flash.  
La cuenta de escalones (`ramp_n`) se lee en `$R` como `N=`.

No se exponen dirty flags ni se pueden forzar calentadores fuera del runner/PID.

---

## Lectura — Soldering Profile `$R`

Solo con `AT+CFG=R?`. Siempre emite los cuatro huecos (0…3); `N` dice cuántos usa HEAT.

```
$R,N=<n>,0=<°C>/<s>,1=<°C>/<s>,2=<°C>/<s>,3=<°C>/<s>
```

Ejemplo: `$R,N=2,0=180/90,1=220/60,2=100/60,3=125/60`.

---

## Recetas rápidas

### Tomar el control y lanzar HEAT

```
AT+MODE=1
AT+CFG=R,0,180,90
AT+CFG=R,1,220,60
AT+CFG=H,0,1
AT+CFG=B,4,6
AT+RUN=1
```

En ese ejemplo: retraso `00:00`, aire on, y el ciclo entra directo en la rampa 1. Bandas ±4 / ±6 °C.

Una espera de 1 h 30 min se escribe `AT+CFG=H,5400,1` (`1×3600+30×60`). El tope es `AT+CFG=H,43200,1` (`12:00`). El equipo no guarda esos segundos: los convierte a hora y minuto.

### Autoajuste

```
AT+CFG=T,5,15,1200
AT+RUN=2,150,5,15,1200
```

- Fuera de rango → `ERROR:2`.
- El `$HP` de sesión (1 Hz) pasa a `A=10` y suma `AP,AC,AK,AI`. No hay segunda trama. Ver «Stream de sesión».
- En medio-ciclo OFF el fan ayuda a bajar.
- Timeout: `AMS` / `max_s` (default **2000** s) → FAIL si se supera.
- Al terminar: copia Kp/Ki a EEPROM, trama con `AP=2` y `AK`/`AI`. No hay `AT+CFG=A`.

Ganancias a mano: `AT+CFG=P,kp,ki`. HotPanel no edita PID ni lanza Auto.

### Parar

`AT+STOP` → **solo `OK`**. Internamente cierra HEAT / aborta autoajuste. Como USB sigue abierto, la foto llega sola en el segundo siguiente.

Pulsar **EXIT** en HotPanel → `ERROR:8` (no es lo mismo que `STOP`).

---

## Qué no tiene comando AT

- `alarm_duration_s` / `alarm_period_s` (solo en firmware / EEPROM).
- Achicar el Soldering Profile: reescribir el último escalón activo (`AT+CFG=R,<n-1>,°C,s` fija N) o `AT+CFG=R,<i>,0,<hold>` con `i≥1`.

---

## Cuándo salen las tramas

| Trama | Cuándo | Fin |
|---|---|-----|
| `$HP` de sesión | Cada 1 s mientras el equipo está en USB (reposo, HEAT o autoajuste) | `AT+MODE=0`, EXIT en HotPanel o reinicio |
| `$HP` (foto) | `STAT?`, `MODE`, cambio de fase, beep de alarma | Un disparo |
| `$CF` | `CFG?` | Un disparo |
| `$R` | `CFG=R?` | Un disparo |

Durante el autoajuste el `$HP` de sesión lleva además `AP,AC,AK,AI`. La trama de DONE o FAIL es la última con esos campos.

## Stream de sesión

Un solo `$HP` a 1 Hz mientras el equipo está en USB. Reposo, HEAT y autoajuste comparten ese emisor. El autoajuste no abre una segunda trama: añade `AP`, `AC`, `AK` y `AI` mientras `ATUNE_RUN`. `$CF` y `$R` siguen bajo demanda.

En el firmware lo arma el tick del sensor en `main.c`: en USB marca la telemetría pendiente y sale una trama por muestra. Un cambio de fase dentro del segundo puede sumar una foto más. Firmware (`avr_uart_init`) y HotPlate Studio (`serial_link.BAUD`) van a 19200; si solo cambia uno, la sesión deja de entenderse.

| Paso | Qué hace el empuje |
|---|---|
| `AT+MODE=1` | Enciende el `$HP` de estado cada 1 s, aunque no haya programa |
| `AT+RUN=1` | La misma trama pasa a contar HEAT (fase, SET, tiempos, duty, `RI`, `FL`) |
| `AT+RUN=2` | La misma trama suma `AP,AC,AK,AI`. Al salir de `ATUNE_RUN` esos campos desaparecen |
| `AT+MODE=0` | Apaga el periódico. En manual solo quedan las fotos de siempre |
| EXIT en HotPanel | `ERROR:8` y vuelta a Manual: el periódico se apaga |
| `AT+STOP` | Sigue siendo solo `OK`. Si USB sigue abierto, la foto siguiente llega en el segundo siguiente |

**Coste medido.** Flash 15676 B frente a 15696 B antes del cambio (−20 B: se reutiliza el formateador y la condición del tick quedó más corta). RAM 283 B y EEPROM 62 B, sin cambios. A 8 MHz, 19200 sale con `UBRR = 25` (19231 reales, error 0,16 %). La transmisión bloquea el bucle unos 34 ms en reposo, 40 ms en HEAT y 49–54 ms en el peor autoajuste (3–5 % del segundo). El muestreo térmico sigue en 1 s y la ventana del PI en 1,5 s. El anillo de recepción es de 32 bytes (31 útiles, ~16 ms a 19200).

**Órdenes del cliente.** HotPlate Studio escribe una línea y espera `OK` o `ERROR` (candado en `serial_link`). Cada orden de producto cabe en el anillo (la más larga, `AT+RUN=2,…`, son 25 bytes). Una orden que llega entera durante el `$HP` no se recorta. Dos escrituras seguidas sin esperar `OK` pueden pasar de 31 bytes: el firmware tira el exceso, descarta la línea y el cliente hace timeout a los 2 s.

La confirmación de guardado y de arranque es `OK` / `ERROR`. EEPROM se escribe antes de ese `OK`. Un `$HP` que llegue mientras el cliente espera no cierra el comando. `AT+STAT?` sigue valiendo como foto. En USB HotPlate Studio pausa su sondeo para no duplicar la trama y lo reanuda al volver a Manual, al recibir `ERROR:8` o al ver el saludo `HP` de un reinicio. El sondeo y un guardado no se cruzan en el cable: comparten el mismo candado.

---

## HotPlate Studio

App de escritorio en [`hotplate-studio/`](../../../hotplate-studio/). Habla este contrato por puerto serie (sin simulador). Cómo arrancarla y cómo está armada: [README](../../../hotplate-studio/README.md) y [arquitectura](../../../hotplate-studio/ARCHITECTURE.md).

```bash
pip install -r hotplate-studio/requirements.txt
python hotplate-studio/app.py
```

---

## Nota de Flash

ATmega16: **16384 B**. Tras tocar el protocolo: `make size` y actualizar [feature_budget.md](feature_budget.md) (skill `hotplate-feature-budget`).  
UI aprobada (iconos, temp ×2) no se sacrifica para meter campos AT opcionales.

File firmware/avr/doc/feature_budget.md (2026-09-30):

# Presupuesto de features (flash / core / minify)

Documento vivo: **actualizar la columna de coste tras cada `make size`** (o al menos tras cada PR que toque firmware).  
**Guardián de agentes:** skill [`.cursor/skills/hotplate-feature-budget/SKILL.md`](../../.cursor/skills/hotplate-feature-budget/SKILL.md) — todos los skills de feature deben invocarlo tras tocar flash/UI.  
Complementa: [product_features.md](product_features.md) · [program_flows.md](program_flows.md) · [architecture.md](architecture.md) · [usb-automation.md](usb-automation.md) · [ui_style_guide.md](ui_style_guide.md) · [pid_control.md](pid_control.md) (C6/C7).

**MCU:** ATmega16 · Flash **16384 B** · Medición: `cd firmware/avr && make size`  
**Última medición de referencia:** Program **16382 B** (100,0 %) · Data **302 B** · EEPROM **62 B** (2026-09-29). Libre **2 B**.

---

## Cómo usar esta tabla

| Columna | Significado |
|---|---|
| **Clase** | `CORE` = no se sacrifica por margen; `SHELL` = UI/adaptador; `CFG` = ajuste AT/EEPROM; `OPT` = opcional / candidato a recorte |
| **Reglas core** | Contrato que no se puede romper |
| **Minify seguro** | Hasta dónde se puede achicar **sin** quitar la feature base |
| **Full deseado** | Estado “aprobado” de producto (hacia dónde volver si hubo regresión) |
| **Coste** | Flash estimado o medido. `Δ` = ahorro/coste al quitar o restaurar. Si no hay Δ, poner “medir” |

### Política de decisión (obligatoria)

1. **Antes** de meter o sacar código: mirar esta tabla + `make size`.
2. **Nunca** financiar una feature nueva quitando **UI aprobada** (iconos 16×16, temp a 2×, glifos/layout de [ui_style_guide.md](ui_style_guide.md)) ni **core térmico** (HEAT/PREHEAT/rampas/PI/safety).
3. Preferir: drivers no usados, AT redundante, flags de producto descartados, algoritmos elegantes pero caros.
4. Tras el cambio: actualizar **Coste** y la fila **Medición global**.

---

## Medición global

| Fecha | Program (B) | Libre | Notas |
|---|---|---|---|
| 2026-09-29 | 16374 | 10 | Sin `FONT_ICONS` ni `FONT_5X7_X2` enlazados (regresión UI). `SND`/`RN`/`KD` fuera de `$CF`. |
| 2026-09-29 | 16588 | −204 | Paso intermedio: S2+S3 re-enlazados sin optimizar (**+214 B**). No cabe |
| 2026-09-29 | 16326 | 58 | + Fase A: F2/U5/U7 fuera (`buzz_nav_*`, `snd`, `kd` de estado/AT/cfg; API buzzer sin `st`) **−262 B** |
| 2026-09-29 | 16128 | 256 | + Fase B: D1 blit de glifos con buffer de bytes y un solo camino COLS/ROWS **−198 B** |
| 2026-09-29 | 16096 | 288 | Icono USB fuera de `FONT_ICONS` (−32 B) y `pid_atune_result` sin kd. Data 289 B. UI aprobada enlazada |
| 2026-09-29 | 16044 | 340 | Pitido de navegación, de arranque, de parada y de salida USB eliminados **−52 B** |
| 2026-09-29 | 15024 | 1360 | Fuera la fase al % de la rampa 1 y `AT+CFG=A` (el autotune escribe Kp/Ki al terminar). Data 286 B **−1020 B** |
| 2026-09-29 | 15536 | 848 | Reloj DLY `hh:mm` (tope 12:00). Base de este cambio de HotPanel. Data 283 B |
| 2026-09-29 | 15696 | 688 | Setup: 2 px bajo el header y 1 px entre filas. Heat: `°C` en la consigna de rampa y `mm:ss` transcurrido. **+160 B**. Data 283 B |
| 2026-09-29 | 15676 | 708 | Stream de sesión: `$HP` a 1 Hz en todo USB (mismo formateador) y UART a 19200. **−20 B**. Data 283 B, EEPROM 62 B |
| 2026-09-29 | 15698 | 686 | Setup: banda invertida de 9 px (1 px sobre y bajo la letra) + 1 px de separación; 4 filas visibles con desplazamiento. **+22 B**. Data 283 B |
| 2026-09-29 | **15924** | **460** | Temperatura en `FONT_8X12` nativa (trazo 2 px) con `°C` y `ERR`; `USB` sigue en 5×7 a 2×. **+226 B**. Data 293 B (+10: descriptor de fuente), EEPROM 62 B |
| 2026-09-29 | **16326** | **58** | Validado con 5 CSV HEAT + 2 autotune: PI Kp ×10/Ki ×100, techo 190 °C, `ERROR:9`, autotune 120…150 °C. TAL/pico/pendiente se calculan en Studio para no ampliar `$HP`. Data 302 B, EEPROM 62 B |
| 2026-09-29 | **16326** | **58** | Techo de consigna **200 °C** (`TEMP_SET_CEILING_C`; antes 190). Corte `temp_max_c` sin cambio: defecto 210, rango 40…250. **0 B**. Data 302 B, EEPROM 62 B |
| 2026-09-29 | **16328** | **56** | Techo de consigna **250 °C** (probado en banco que la placa pasa de 200). Rango del corte `temp_max_c` 40…**260** (defecto 210 sin cambio). **+2 B**. Data 302 B, EEPROM 62 B |
| 2026-09-29 | **16368** | **16** | STOP en `ALM` llama `program_user_ack` (HotPanel y `AT+STOP`) y sigue a `AIR`. **+40 B**. Data 302 B, EEPROM 62 B |
| 2026-09-29 | **16382** | **2** | Home repinta todo al cambiar de fase (antes `END`/`ERR` dejaban `RUN` congelado). **+14 B**. Data 302 B, EEPROM 62 B |

---

## Tabla de features / programas / subprocesos / CFG

| ID | Feature / pieza | Clase | Reglas core | Minify seguro | Full deseado | Coste (flash) |
|----|---|---|---|---|---|---|
| C1 | **Scheduler cooperativo** (super-loop, ticks, delays no bloqueantes) | CORE | Sin `_delay_ms()` en caminos calientes; ver [temporizacion_no_bloqueante.md](temporizacion_no_bloqueante.md) | Compactar helpers; no fusionar en un solo hilo bloqueante | Mantener | Incluido en `main` + `avr_delay` · **medir Δ** si se toca |
| C2 | **AppState + ConfigStore** (EEPROM v8, única fuente de verdad) | CORE | Ver distinta → defaults; salidas OFF en fault; dirty telem | Compactar validación; no fragmentar estado | EEPROM v8 + bandas BN/BX | `cfg_store.c` grande en fuente · **medir** |
| C3 | **Programa HEAT** (DELAY→PREHEAT→RUN/HOLD→ALARM→COOL→DONE) | CORE | Rampas no decrecientes; no mezclar USB+MANUAL; aire solo al final | Acortar strings de fase; no quitar fases | Perfil SMD usable en banco | `program_runner` · **medir** |
| C4 | **PREHEAT** (fase, no programa AT) | CORE | % de Ramp1; meseta + histéresis; overheat timeout | Ajustar defaults; no eliminar fase | `preheat_en`/`pct`/`stabilize`/`BN`/`BX` | Parte de C3 |
| C5 | **Rampas** (dato EEPROM, approach + meseta `hold_s`) | CORE | Approach PI controlado; `hold_s` solo en HOLD; no decrecientes | Menos escalones en UI no reduce flash de lógica | 4 huecos + `$R` | Parte de C3 + `CFG=R` |
| C6 | **PI predictivo** (`t_ref` + lookahead, anti-windup) | CORE | Duty → SSR; Kd lazo = 0; `pid_on_set_step` entre SET | Tunear RISE/LOOKAHEAD compile-time; no quitar gobernador | Precisión sin overshoot grave. Kp ×10; Ki ×100; integral cuantizado cada 10 s | Incluido en medición **16326 B** |
| C7 | **Autotune** (`PID_TUNE`, solo AT) | CORE (USB) | Solo `AT+RUN=2`; consigna **120…150 °C**; al terminar copia Kp/Ki. `FAIL` sin EEPROM si ON ≥ 3× el OFF anterior o 180 s plano | Compactar Z–N; no quitar el copiado a EEPROM | Mismos campos `AP/AC/AK/AI` en el `$HP` de sesión, sin segunda trama | Incluido en medición **16326 B** |
| C8 | **Safety / overtemp / sensor fault** | CORE | PTC OFF; `ERROR:7` / FAULT | Sin minify funcional | Mantener | `safety` + hooks · **medir** |
| C9 | **Alarmas de proceso** (`ALARM:2`, beeps READY/FAULT) | CORE | Fin HEAT → alarma; cancel UI ≠ ALARM USB. STOP en `ALM` cierra el aviso y pasa a `AIR` | Fijar reps; no quitar ALARM:2 | Mantener beeps de **proceso** | Ack de `ALM` **+40 B** (16328 → 16368) |
| S1 | **Home Heat \| Settings** (2 casillas, overlays) | SHELL | Nunca vistas USB/Settings aparte; dirty rows; i18n | Compactar `home_view` sin cambiar layout | Layout [ui_style_guide](ui_style_guide.md) | Aire de Setup + `°C` de rampa + transcurrido **+160 B** (15536 → 15696). Filas de Setup de 9+1 px con desplazamiento **+22 B** (15676 → 15698) |
| S2 | **Iconos sidebar 16×16** (`FONT_ICONS`) | SHELL / **APROBADO** | Contrato visual; no sustituir por letra si hay margen | Comprimir glifos; 2 iconos | **Enlazado** Heat/CFG (+ USB si cabe) | S2+S3 juntos **+214 B** medido · **enlazado** Heat/CFG + separador x=31; USB solo con `-DFONT_ICONS_USB` (+32 B) |
| S3 | **Temperatura `FONT_8X12`** (+ título USB en `FONT_5X7_X2`) | SHELL / **APROBADO** | Temp legible centrada con `°C` | Tabla solo `-.0-9°CER`; no bajar a 5×7 1× salvo emergencia documentada | **8×12 nativa en Heat/USB**, `USB` a 2× | `font8x12` **+226 B** (15698 → 15924) · **enlazado** |
| S4 | **i18n CAPS** (fases / footer) | SHELL | Textos vía `i18n_tr_hash` | Strings más cortos | Labels actuales | Pequeño · **medir** |
| U1 | **Sesión USB** (`AT+MODE`, mutex manual) | CORE-IF | USB y MANUAL no activos a la vez | — | Mantener | `device_session` + AT · **medir** |
| U2 | **Telemetría `$HP`** (T, fase A, SET, DU, RI, …) | CORE-IF | Una trama a 1 Hz en toda la sesión USB, UART 19200, enriquecida en autotune. No tres formateadores | Quitar campos raros; no quitar A/SET/DU/RI | Chart fases + potencia; Studio deriva TAL/pico/pendiente desde T | `telemetry` · stream de sesión **−20 B** |
| U3 | **`$CF` / `$R`** | CFG | Lectura bajo demanda | `KD`/`SND` ya no existen; `RN` omitido | BN/BX/PH/PCT/SB/S/P/AMS + `$R` | Ya minificado parcial |
| U4 | **`AT+CFG=S`** límites | CFG | min≤max, rangos producto | — | Mantener | Bajo |
| U5 | **`AT+CFG=H`** flujo HEAT | CFG | delay 0…43200 s (se guarda h+m), air | **Hecho:** `snd` fuera (6.º argumento → `ERROR:2`) | H sin sonido nav. Reloj hasta 12:00 | Incluido en la medición 15536 |
| U6 | **`AT+CFG=B`** bandas | CFG | bn≤bx | Valorar fusionar en H si cabe línea AT | Mantener BN/BX | Bajo–medio |
| U7 | **`AT+CFG=P`** PID | CFG | Kp/Ki | **Hecho:** `P,kp,ki`; `pid_kd_x10` eliminado del estado (EEPROM: bytes reservados) | Mantener P | Parte de los −262 B de la Fase A |
| U8 | **`AT+CFG=T` / `RUN=2`** | CFG | Solo USB. No existe `CFG=A` | Compactar parse | Mantener | Medio |
| U9 | **`AT+CFG=R` / `R?`** | CFG | Perfil no decreciente y cada escalón ≤ techo de consigna (250 °C, o `temp_max_c` si es menor) | — | Mantener | Incluido en medición **16328 B** |
| F1 | **Flag `cooldown_air_en`** | CFG | Fan solo cooldown final | — | Mantener | Bajo |
| F2 | **Sonido de navegación** | OPT / **DESCARTADO** | Beeps de proceso y el pulso al guardar se quedan | **Hecho:** fuera de estado, `CFG=H`, HotPlate Studio y de HotPanel (cursor, RUN, STOP, EXIT). EEPROM v8 conserva los bytes como `rsv` | **Fuera** | Fase A −262 B; quitar las llamadas del panel **−52 B** |
| D1 | **Driver ST7920** (draw/text/config) | SHELL-DRV | Home usa `draw_band` / GDRAM / clear | La API geométrica ya no se enlazaba (gc-sections). **Hecho:** blit con `uint8_t row[16]` y un solo `st7920_glyph_row` para COLS (1×/2×) y ROWS | Solo API usada por Home | **−198 B** medido. `draw_band` 342 B + `glyph_row` 268 B |
| D2 | **MAX31865 + soft SPI** | CORE-DRV | Lectura válida para PID/safety | — | Mantener | Necesario |
| D3 | **Fonts** `font5x7` + `font8x12` + icons | SHELL | Guía UI | `font8x12` solo con los glifos de temperatura (`tools/gen_fonts.py`) | 5×7 + 8×12 + icons + X2 (USB) | icons ver S2; 8×12 ver S3 |

---

## Matriz rápida: ¿de dónde sacar flash?

| Prioridad | Acción | ¿Rompe core/UI aprobada? | Notas |
|---|---|---|---|
| ~~P0~~ | ~~Restaurar **S2 + S3**~~ | — | **Hecho** 2026-09-29 |
| ~~P1~~ | ~~Recortar **ST7920** (D1)~~ | — | **Hecho** (−198 B) |
| ~~P2~~ | ~~Eliminar **F2**~~ | — | **Hecho** |
| ~~P3~~ | ~~Acortar **U5**~~ | — | **Hecho** |
| P4 | Compactar parse AT / `$CF` redundante | No si se mantiene chart | Cuidado con HotPlate Studio |
| P5 | Micro-opts PID/autotune (mismo comportamiento) | No si tests verdes | No “elegancia” cara |
| **Prohibido** | Quitar iconos / temperatura 8×12 / HEAT / PI / safety para meter otra feature | Sí | Ya ocurrió; no repetir |

---

## Procedimiento de actualización

```bash
cd firmware/avr && make clean && make && make size
# Anotar Program/Data/EEPROM en “Medición global”
# Si el PR toca una fila: actualizar Coste (Δ medido) y Full vs actual
make usb-host-test flow-host-test
```

Historial breve de Δ conocidos (aprox., LTO):

| Cambio | Δ Program (aprox.) |
|---|---|
| Quitar enlace `FONT_ICONS` + uso `FONT_5X7_X2` (medido juntos, driver antiguo) | −214 B |
| Quitar un `kv_u` de `$CF` | −15…25 B |
| F2 + U5 + U7 (sonido nav, `snd`, `kd`) | −262 B |
| D1 blit de glifos en bytes | −198 B |
| Icono USB fuera de `FONT_ICONS` | −32 B |
| Aire de Setup (2 px / 1 px) + `°C` en la fila de rampa + `mm:ss` transcurrido | +160 B |
| Temperatura en `FONT_8X12` nativa, con `°C` y `ERR` | +226 B |

---

## Relación con otros docs

- Qué debe hacer el producto: [product_features.md](product_features.md)  
- Cómo fluye: [program_flows.md](program_flows.md)  
- Capas: [architecture.md](architecture.md)  
- AT: [usb-automation.md](usb-automation.md)  
- UI: [ui_style_guide.md](ui_style_guide.md)  
- Plan de trabajo para recuperar margen **sin** romper lo de arriba: [optimization_plan.md](optimization_plan.md)

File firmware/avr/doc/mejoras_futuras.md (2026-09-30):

# Erratas y mejoras futuras

Registro térmico y decisiones de banco. Los cambios de la sección 4 ya están
implementados; el contrato vigente sigue en [program_flows.md](program_flows.md)
y [pid_control.md](pid_control.md).

Fecha: 2026-09-29.  
Aleación de referencia: **Sn63/Pb37** (eutéctico **183 °C**).  
Techo físico declarado de la placa: **190 °C**. En el repositorio no hay ninguna traza que lo mida.

Perfil de horno usado solo como forma de referencia (es de soldadura sin plomo; liquidus ≈ 217 °C, pico 260 °C): imagen de resina y [Reflow soldering profile](https://www.superengineer.net/blog/soldering-reflow-profile#rsp).

---

## 1. Qué dicen las trazas reales

Las capturas y CSV están en `docs/heat-results/`, `docs/atune-results/` y
`firmware/avr/doc/ultimo-heat/`. Las primeras trazas HEAT todavía nombran
`Precalentado` / `Estabilizando`; sirven para la **planta** (inercia, pendiente,
cola, enfriamiento), no para copiar aquella máquina de estados.

La última traza llega a **171,7 °C** con SET 175 °C. No hay muestras a 183 °C
ni cerca del techo de 190 °C; el pico y el TAL del perfil final siguen sin
validación real.

La regresión reproducible es `make real-trace-test`: consume los cinco CSV HEAT
y los dos de autotune. Verifica que el PI anterior reproduce el duty del atasco
(32 %), que la escala corregida recupera autoridad (~59 % en ese estado), que
ninguna corrida real daría un falso `ERROR:9` y que las oscilaciones reales no
disparan el rechazo ON ≥ 3× OFF.

### Subida a plena potencia (autotune, SET 100 °C)

`hotplate_tune_trace-2.csv` y `hotplate_tune_trace_ajustado.csv`, primer tramo con el calentador al 100 %:

| Tramo | Tiempo | Pendiente |
|---|---|---|
| ~30 → 50 °C | 94–96 s desde el arranque | 0,36–0,39 °C/s |
| 50 → 60 | 20–21 s | 0,47–0,50 °C/s |
| 60 → 70 | 16–18 s | 0,55–0,63 °C/s |
| 70 → 80 | 13–15 s | 0,66–0,77 °C/s |
| 80 → 90 | 14 s | 0,72 °C/s |
| 90 → 100 | 13–14 s | 0,71–0,75 °C/s |
| 30 → 100 | **173–176 s** | media ≈ 0,40 °C/s |

A 100 °C la planta **todavía acelera**. Ese punto no es el techo.

Al cortar el SSR en 101,5 °C la temperatura siguió hasta **117,8 °C (+16,3 °C) en 41 s**, ya con el calentador apagado. Esa cola es de un corte brusco a ~0,7 °C/s. No es el overshoot de un escalón PI de 10 °C.

### HEAT en lazo cerrado, hasta 130 °C

`hotplate_heat_trace-4.csv` es la corrida usable (placa ya a 65 °C, escalones de 10 °C):

| Escalón | Approach hasta la banda | Qué hizo la meseta |
|---|---|---|
| 80 °C | 84 s hasta 76 °C | 31 s: 75 → 78 °C, sin pasarse |
| 100 °C | 71 s, 78 → 95 °C, duty medio 66 % | **30 s no aplanan**: 95 → **103,4 °C** (+3,4 °C) con duty ~2 % |
| 110 °C | 51 s, ya venía en 103 °C | 60 s: 105 → 107 °C |
| 120 °C | 60 s, 107 → 115 °C, duty ~48 % | 30 s: 115 → 119,6 °C (no llega al SET) |
| 130 °C | 58 s, 120 → 125 °C, duty ~46 % | 30 s: 125 → **129,3 °C** |

Consecuencias para elegir tiempos:

- Una meseta de **30 s no es un soak**. En el primer escalón la temperatura sigue subiendo todo el `hold_s`.
- **60 s** solo aplana si al entrar ya se está a menos de ~5 °C del SET.
- A 120–130 °C el PI iba a **~45 %** de duty. Ahí todavía había margen de potencia; la lentitud de esos escalones no demuestra el techo de 190 °C.
- El overshoot del PI, en escalones de 10 °C, fue de **+3,4 °C** una vez y en el resto se quedó por debajo del SET.

`hotplate_heat_trace-3.csv` es el caso contrario y no debe usarse como perfil: entre 110 y 130 °C tardó **7–10 min por cada 10 °C**, con duty ~30 %, y se quedó regulando en **SET − 4 °C** (96, 106, 116 y 126 °C). El lookahead y las ganancias pueden frenar la rampa aun teniendo potencia. Un soak de esa corrida no existe: el `hold_s` corre en el borde inferior de la banda.

`hotplate_heat_trace-2.csv` se quedó ~20 min oscilando en 78 °C dentro del precalentado antiguo. No aporta pendientes de reflow.

### Enfriamiento con aire, al terminar

Pendiente medida al bajar (alarma + enfriamiento). El máximo de la imagen de referencia es 6 °C/s; esta placa está muy por debajo.

| Traza | 130 → 120 | 120 → 110 | 100 → 90 | 60 → 50 | 130 → 50 |
|---|---|---|---|---|---|
| heat-trace-3 | 0,19 °C/s | 0,19 °C/s | 0,15 °C/s | 0,05 °C/s | 741 s |
| heat-trace-4 | 0,15 °C/s | 0,16 °C/s | 0,11 °C/s | 0,04 °C/s | 1039 s |

La bajada empinada del perfil de horno **no se puede dibujar**. El ventilador solo actúa al final. De 190 a 183 °C, si la pendiente se pareciera a la de 130 °C (~0,15 °C/s), harían falta unos **45 s** después de cortar el calor. Ese tiempo se suma al TAL y no está medido a 190 °C.

---

## 2. Qué no se copia de la gráfica de horno

| Dato de la gráfica (sin plomo) | En esta placa, con Sn63/Pb37 |
|---|---|
| Liquidus ≈ 217 °C, pico 260 °C | Liquidus **183 °C**. El pico de sensor no puede pasar de **190 °C**. |
| ≤ 8 min hasta el pico | 30 → 100 °C ya cuesta **3 min** a plena potencia. No hay medición de 100 → 190. No usar 8 min como objetivo ni como límite. |
| Subida típica 1–2 °C/s, tope 3 °C/s | Máximo medido **0,75 °C/s** a plena potencia, cerca de 100 °C. El tope de 3 °C/s se cumple solo. |
| Soak largo 150 → 200 °C | Entre 183 y 190 °C solo hay 7 °C. El tramo lento hay que dejarlo **por debajo de 183 °C**. |
| 10 s en el pico y 30 s dentro de 5 °C del pico | Eso limita el estrés a ~260 °C. A 190 °C no se copia como meseta de 10 s. |
| TAL 60–150 s sobre liquidus | Para Sn63/Pb37 el ensayo busca **30–90 s sobre 183 °C en la unión**, medidos con termopar. El `hold_s` del firmware no es ese tiempo: empieza cuando el sensor de la placa entra en SET ± 4 °C. |
| Enfriamiento 2–4 °C/s, máximo 6 | Medido **0,04–0,19 °C/s**. Cumple el máximo por ser mucho más lento. |

---

## 3. Perfil experimental de cuatro escalones

Valores elegidos para HotPanel: temperatura en pasos de 5 °C y meseta en pasos de 30 s. Rampas solo ascendentes. `DLY` `00:00`. Banda `BN` = 4 °C. Dejar `temp_max_c` en **210 °C** en el ensayo: si se pone en el techo de consigna (200 °C), una lectura de 200,0 °C dispara `ERROR:7` y corta el calor.

| Escalón | °C | `hold_s` | Por qué este valor |
|---|----|---|---|
| R1 | **150** | **120 s** | Meseta análoga al precalentamiento de 60–120 s de la gráfica, en temperatura absoluta de activación del flux. 30 s no aplanaron en trace-4; 120 s da tiempo a que la cola caiga y el tramo se vea plano. 150 + 3,4 °C de overshoot PI ≈ 153 °C, lejos de 183. |
| R2 | **165** | **90 s** | Segundo tramo del soak, todavía 18 °C bajo el liquidus. Cubre el overshoot de +3,4 °C y aun una cola mayor (165 + 16 °C de corte brusco = 181 °C, justo por debajo de 183). 90 s está dentro de la ventana 60–120 s y, a diferencia de 30 s, sí puede estabilizar. |
| R3 | **175** | **60 s** | Hombro antes del pico. No 180 °C: 180 + 3,4 °C ya roza 183 °C y fundiría durante el soak. 60 s basta porque el salto es de 10 °C, igual que los escalones que en trace-4 entraron en banda en ~60 s; la meseta solo remata. |
| R4 | **190** | **90 s** | Pico en el techo declarado. 90 s es el centro del TAL habitual de 30–90 s. No 120–150 s: el enfriamiento medido es tan lento que, si la unión sigue a la placa, otros ~45 s por encima de 183 °C llegan **después** de cortar. |

Rampa de respaldo si el primer ensayo en vacío pasa de 160 °C al final de R1 (la cola de +16 °C del autotune, no la de +3 °C del PI):

| Escalón | °C | `hold_s` |
|---|----|---|
| R1 | 140 | 120 s |
| R2 | 160 | 90 s |
| R3 | 190 | 90 s |
| R4 | off | — |

Se pierde el hombro de 175 °C. La curva se parece menos a la silla de la gráfica y gana margen bajo 183 °C.

### Cómo se verá respecto a la gráfica

- De ambiente a 150 °C el approach **no cuenta** dentro de los 120 s. Esos 120 s empiezan al cruzar 146 °C en el sensor de la placa.
- 30 → 100 °C medido: ~3 min a plena potencia. De 100 a 190 °C no hay dato. Aunque la pendiente de 0,7 °C/s se mantuviera, 100 → 190 °C serían ~2 min; junto al techo la pendiente tiene que caer a cero, así que el tramo final será más largo. El total hasta el pico puede superar los 8 min de la gráfica sin que eso indique un fallo.
- La forma esperable es una escalera de cuatro peldaños, no la curva continua del horno. Con estos saltos (15, 10 y 15 °C) se evita tanto la escalera de 10 °C de trace-4 como un único salto hasta 190 °C.
- La bajada será una cola larga (del orden de 12–17 min de 130 a 50 °C en las trazas), no el flanco de la imagen.

### Criterio para aceptar o corregir el ensayo

Primer ciclo **sin pasta**, sensor de la placa. Segundo ciclo con termopar en un pad.

1. Cresta de R1 ≤ 160 °C y de R2 ≤ 175 °C. Si no, usar el perfil de respaldo.
2. Cresta de R3 ≤ 183 °C. Si la pasta funde en R3, bajar R3 a 170 °C.
3. La unión debe pasar de 183 °C. Si no ocurre con R4 a 190 °C, el techo físico no alcanza para esa PCB.
4. Tiempo de la **unión** sobre 183 °C: 30–90 s. Si el enfriamiento lo alarga por encima de 90 s, bajar el `hold_s` de R4 a 60 s. Si no llega a 30 s, subirlo a 120 s. No subir el SET por encima de 200 °C.
5. Si un escalón se queda más de 3 min con duty ≥ 95 % y la temperatura no entra en SET − 4 °C, ese SET es inalcanzable. Hoy `PH_RUN` no tiene timeout: parar a mano.

---

## 4. Cambios de algoritmo

Están en el firmware. El techo de consigna es 250 °C (antes 200; en banco la placa pasa de 200 °C) y el corte de seguridad por defecto es 210 °C.

### 4.1 Consigna de proceso distinta del corte de seguridad

`temp_max_c` (defecto **210 °C**, rango 40…260) sigue siendo el corte de `safety_apply_limit`: al llegar, calefactor OFF y `ERROR:7`.

El techo de consigna es `TEMP_SET_CEILING_C` (**250 °C**), o `temp_max_c` si ese corte es más bajo. Para usar escalones de más de 200 °C hay que subir `temp_max_c` unos °C por encima del escalón más alto. `AT+CFG=R`, el editor de HotPanel y `AT+RUN=1` rechazan un escalón por encima. Una placa ya grabada con un escalón más alto no arranca (`ERROR:2`) hasta que se baje.

### 4.2 Consigna inalcanzable y timeout de `PH_RUN`

Si durante **180 s** el duty es ≥ 95 %, la pendiente es ≤ 0,2 °C/s y `T` sigue por debajo de la banda de entrada, el ciclo corta el calor, pasa a `FAULT` y emite `ERROR:9`. No es el corte de `temp_max_c`.

### 4.3 El `hold_s` no mide el TAL

HotPlate Studio calcula con las muestras `T` los segundos de la **placa** ≥
183 °C (`TL` en su panel), también en la bajada, además del primer cruce, pico y
pendiente máxima. No se añade otro campo a `$HP` por el límite de flash. El
tiempo válido de la unión sigue siendo un termopar en la PCB.

### 4.4 Autotune lejos del techo

`AT+RUN=2` y `pid_atune_start` solo aceptan **120…150 °C** (y dentro de Tmin…Tmax−10). Si un semiperiodo ON es ≥ 3× el OFF anterior, o la subida se queda plana 180 s sin cruzar el umbral alto, termina en `FAIL` y no escribe Kp/Ki.

`LOOKAHEAD_S_DEFAULT` sigue en 15 s.

### 4.5 Enfriamiento

No hay rampa de bajada ni una pendiente objetivo de 2–4 °C/s. El aire solo
actúa al final. Studio sigue contando mientras la placa permanece sobre 183 °C
después del corte.

### 4.6 Fuera de este documento

Más potencia, mejor aislamiento o completar el pico con aire caliente son cambios de hardware o de proceso. No los resuelve el PI. Sin una unión que supere 183 °C con carga, los puntos 4.1–4.5 solo evitan que el ciclo se quede calentando; no crean el perfil de horno.

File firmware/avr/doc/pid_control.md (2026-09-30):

# Control térmico de HotPlate — PI predictivo y autoajuste

Guía **autosuficiente** para entender y portar el mismo comportamiento a otros proyectos, agentes o skills.

| Dónde está el código | Para qué |
|---|---|
| `firmware/avr/src/services/pid.c` | Lazo de trabajo |
| `firmware/avr/src/services/pid_atune.c` | Autoajuste |
| `firmware/avr/src/app/app_config.h` | RISE, LOOKAHEAD, ventana SSR |
| [program_flows.md](program_flows.md) | Cuándo corre en el ciclo HEAT |

**De un vistazo**

- Planta: HotPlate con mucha inercia (PTC), sensor lento (~1 Hz), actuador on/off (SSR).
- Lazo de trabajo: **PI** (sin D) con referencia que sube a ritmo limitado y **anticipación** de la cola térmica.
- Identificación: oscilación todo/nada → Ziegler–Nichols método 2, regla **PI**.

---

## 1. Cómo se miden las cosas en el firmware

En el micro casi todo va en enteros. Las temperaturas se guardan **×10** (una décima de grado = 1 unidad).

| Símbolo | En el firmware | En la vida real |
|---|---|---|
| `T` | °C × 10 (`temp_c_x10`) | Temperatura medida |
| `t_set` | °C enteros | Consigna de la etapa (Soldering Profile) |
| `t_ref` | °C × 10 | Referencia interna que el lazo persigue (no es el SET de golpe) |
| `rate` | (°C × 10) / muestra | Cuánto subió o bajó T desde la muestra anterior (~°C×10 por segundo si la muestra es 1 s) |
| `Kp` | entero × 10 | Ganancia proporcional (`pid_kp_x10`) |
| `Ki` | entero × 100 | Ganancia integral por segundo (`pid_ki_x10`; nombre interno heredado) |
| `duty` | 0…100 % | Parte de cada ventana en la que el calefactor está ON |
| `I` | acumulador × 10 | Integral del error (con anti-windup) |

Un cálculo del lazo = **una muestra de temperatura** (`TEMP_PERIOD_MS`, por defecto **1000 ms**).

---

## 2. Cómo está armado el lazo

```mermaid
flowchart LR
  SET[Consigna t_set] --> GOV[Gobernador t_ref]
  T[T medida] --> RATE[rate = ΔT]
  GOV --> ERR
  T --> PRED[T_pred = T + rate·L]
  RATE --> PRED
  PRED --> ERR[error = t_ref − T_pred]
  ERR --> PI[PI → duty]
  PI --> WIN[Ventana ON/OFF]
  WIN --> SSR[Calefactor]
```

Idea simple: no pedimos el SET de golpe. Subimos una referencia interna, miramos un poco al futuro (porque HotPlate sigue calentando después de cortar) y con ese error calculamos cuánta potencia aplicar.

### 2.1 Cuándo corre

| Situación | Qué hace |
|---|---|
| Sensor válido y lazo en AUTO | Calcula una muestra (`pid_compute_sample`) |
| Fases típicas de HEAT | Precalentamiento, estabilización, subida, meseta |
| Cada vuelta del programa | Aplica el duty a la ventana SSR (`pid_window_tick`) |
| Arranque / parada / fallo / aplicar autoajuste | `pid_reset` (limpia I y rate; `t_ref` = T actual) |
| Nuevo SET de rampa (sin tocar I) | `pid_on_set_step`: rate = 0, `t_ref` = T |

### 2.2 Gobernador de referencia (`t_ref`)

Objetivo: no exigir el SET de golpe (evita saturar y pasarse de temperatura por inercia).

Cada muestra (~1 s):

- Si `t_ref` aún está por debajo del SET × 10:

$$
t_{\mathrm{ref}} \leftarrow \min(t_{\mathrm{set}} · 10,\ t_{\mathrm{ref}} + R)
$$

- Si no (ya alcanzó o el SET nuevo es menor o igual):

$$
t_{\mathrm{ref}} \leftarrow t_{\mathrm{set}} · 10
$$

| Variable | Default | Qué cambia si la mueves |
|---|---|---|
| `RISE_C_X10_DEFAULT` ($R$) | **12** (= 1,2 °C/s con muestra de 1 s) | Qué tan rápido “pide” subir la referencia |

Subir $R$ → llega antes, más riesgo de cola. Bajar $R$ → más lento y suave.

En el Soldering Profile (solo ascendentes), HotPlate no rampa hacia abajo: si el SET nuevo es ≤ `t_ref`, salta al SET.

### 2.3 Anticipación de cola (lookahead)

Primero se estima la velocidad de cambio:

$$
\dot{T} \approx \mathtt{rate}
\quad\text{(por muestra)}
$$

Luego la temperatura “que habrá” dentro de $L$ segundos (con tope para no desbordar enteros):

$$
T_{\mathrm{pred}} = T + \mathrm{clip}(\dot{T} · L,\ ±5000)
$$

Y el error que ve el PI:

$$
e = t_{\mathrm{ref}} - T_{\mathrm{pred}}
$$

| Variable | Default | Qué cambia si la mueves |
|---|---|---|
| `LOOKAHEAD_S_DEFAULT` ($L$) | **15** s | Anticipación del corte. Con $L = 15$ y 1,2 °C/s ≈ **18 °C** de margen mental |

$L$ grande → corta lejos del SET (más preciso, más lento cerca).  
$L$ pequeño → más agresivo, más overshoot.

El clip ±5000 (= ±50 °C en la predicción) evita overflow en enteros.

### 2.4 PI y anti-windup

Si el duty **no** está saturado a favor del error, el modelo ideal actualiza:

$$
I \leftarrow \mathrm{clip}(I + e,\ ±10000)
$$

En el ATmega16 se usa la forma equivalente cuantizada: cada 10 muestras se
acumula el error actual en `I10`, con tope ±1000. Así `I10 ≈ I/10` y se evita
enlazar una división signed de 32 bits que no cabe en el flash:

$$
I_{10} \leftarrow \mathrm{clip}(I_{10} + e,\ ±1000)
\quad\text{cada 10 muestras}
$$

Salida interna (0…1000) y duty en %:

$$
u = \mathrm{clip}\left(\frac{K_{p,x10} · e + K_{i,x100} · I_{10}}{10},\ 0,\ 1000\right)
$$

$$
\mathrm{duty\%} = u / 10
$$

$K_p$ se guarda ×10 y $K_i$ ×100. El nombre interno `pid_ki_x10` se
conserva por compatibilidad, pero su unidad real es ×100. El firmware anterior
dividía el término integral por 100; debía dividirlo por 10. Eso lo dejaba diez
veces corto y el lazo se equilibraba varios grados bajo el SET.

**No integrar** cuando ya no sirve: `(duty ≥ 100 y e > 0)` o `(duty = 0 y e < 0)`.

| Variable | Origen | Qué hace |
|---|---|---|
| `pid_kp_x10` | EEPROM / `AT+CFG=P` / autoajuste | Respuesta al error predicho |
| `pid_ki_x10` | igual; unidad real ×100 | Quita el error residual en meseta; demasiado alto → oscilación lenta |
No hay Kd: ni en `app_state_t`, ni en EEPROM, ni en `AT+CFG=P` (en térmicas lentas el Td de Z–N satura).

Valores de fábrica de referencia: Kp_x10 = **246** (24,6),
Ki_x100 = **10** (0,10/s).

### 2.5 Ventana time-proportioning (SSR)

Cada `PID_WINDOW_MS` (default **1500 ms**):

$$
t_{\mathrm{ON}} = \mathrm{duty\%} × \mathtt{PID\_WINDOW\_MS} / 100
$$

El calefactor está ON mientras `elapsed < t_ON` (con 0 % y 100 % saturados).

| Variable | Influye en |
|---|---|
| `PID_WINDOW_MS` | Granularidad del pulso SSR — **no** la pendiente de acercamiento al SET |

El actuador de referencia es opto + triac (SSR). Se puede sustituir por otro on/off si el duty sigue significando “fracción de potencia”.

### 2.6 Cambio de etapa (`pid_on_set_step`)

Al pasar a un nuevo SET (por ejemplo Ramp i):

1. `rate ← 0` — no heredar la velocidad del tramo anterior (evita un duty = 0 fantasma).
2. `t_ref ← T` actual — el gobernador vuelve a subir desde la temperatura real.
3. **No** se pone I = 0 — transición suave entre rampas.

Sin este paso, un lookahead residual del precalentamiento puede apagar el calefactor al entrar en Ramp1.

---

## 3. Cómo afinar en banco

Orden recomendado (primero lo de compilación):

| Prioridad | Parámetro | Si llega lento cerca del SET | Si se pasa de temperatura |
|---|---|---|---|
| 1 | `LOOKAHEAD_S_DEFAULT` | Bajar (p. ej. 30 → 18 → 15) | Subir |
| 2 | `RISE_C_X10_DEFAULT` | Subir (7 → 10 → 12) | Bajar |
| 3 | `pid_kp_x10` / `pid_ki_x10` | Autoajuste o subir Kp con cuidado | Bajar Ki o Kp |
| 4 | `PID_WINDOW_MS` | Solo si el SSR “chapotea”; poco impacto en el tiempo total | — |

Punto de partida validado en HotPlate SMD de inercia alta: RISE ≈ 0,7–1,2 °C/s, LOOK 15–30 s, PI de autoajuste.  
Valores actuales en firmware: **RISE = 1,2 °C/s**, **LOOK = 15 s**.

---

## 4. Autoajuste (aprender la planta)

### 4.1 Idea

Forzar una oscilación alrededor de `t_set` encendiendo y apagando al 100 % (bang-bang con histéresis), medir el periodo $T_u$ y la amplitud $A$, calcular la ganancia límite $K_u$ y aplicar Ziegler–Nichols **PI**.

### 4.2 Parámetros

| Variable | Rango típico | Default | Rol |
|---|---|---|-----|
| `t_set_c` | **120…150** °C, y dentro de [Tmin .. Tmax−10] | — | Centro de oscilación. Fuera de 120–150 el relé no tiene autoridad y `RUN=2` responde `ERROR:2` |
| `atune_hyst_c_x10` | 1…99 | **15** (±1,5 °C) | Ancho del relé: ON hasta SET+hyst, OFF hasta SET−hyst |
| `atune_cycles_target` | 3…10 | **5** | Ciclos a acumular (tras descartar el heat-up) |
| `atune_max_s` | 120…3600 | **2000** | Tiempo máximo → FAIL |

### 4.3 Qué hace muestra a muestra (~1 s)

1. **ON:** calefactor 100 %, fan OFF. Sigue mientras $T < SET + hyst$. Al cruzar el umbral alto → OFF, fan ON (acelera la bajada), acumula semiperiodo.
2. **OFF:** calefactor 0 %, fan ON. Sigue mientras $T > SET - hyst$. Al cruzar el umbral bajo → ON, fan OFF, acumula semiperiodo.
3. Tras el **2.º** flanco (fin del primer medio ciclo de calentamiento), **reinicia** los picos $T_{\max}$ / $T_{\min}$ para no contar el transient inicial.
4. Cuando hay suficientes ciclos cerrados y semiperiodos → termina OK, salvo que un semiperiodo ON sea ≥ 3× el OFF anterior: en ese caso `FAIL` y no se escribe EEPROM.
5. Si el calefactor lleva **180 s** en ON, la temperatura sigue bajo el umbral alto y la pendiente es ≤ 0,2 °C/s, el pico está aplastado: `FAIL` sin escribir Kp/Ki.

### 4.4 Fórmulas (como en el firmware)

Todo esto ocurre en **`firmware/avr/src/services/pid_atune.c`**: al cerrar el último ciclo se calculan $A$ y $T_u$ en `pid_atune_on_sample`, y con ellos $K_u$, $K_p$ y $K_i$ en `finish_ok`.

#### Paso 1 — Amplitud de la oscilación ($A$)

**Qué responde:** “¿Qué tan grande fue el vaivén de temperatura alrededor del SET?”  
Cuanto mayor $A$, más “floja” parece la planta frente al relé; eso baja la ganancia límite.

$$
A = \frac{T_{\max} - T_{\min}}{2}
$$

($A$ en °C × 10. Si sale menor que 5, el firmware la sube a 5 para no dividir por casi cero.)

```179:182:firmware/avr/src/services/pid_atune.c
        if ((s_half_n / 2u) >= st->atune_cycles_target && s_half_n >= 4u) {
            uint16_t tu_s = (uint16_t)((s_half_sum_s * 2u) / (uint16_t)(s_half_n - 1u));
            int16_t amp = (int16_t)((s_peak_hi - s_peak_lo) / 2);
            finish_ok(st, tu_s, amp);
```

(`s_peak_hi` / `s_peak_lo` se actualizan cada muestra un poco más arriba en la misma función; tras el 2.º flanco se reinician para ignorar el heat-up.)

#### Paso 2 — Periodo de oscilación ($T_u$)

**Qué responde:** “¿Cuánto tarda un ciclo completo ON→OFF→ON?”  
Ese tiempo es el periodo crítico $T_u$; de ahí saldrá el tiempo integral $T_i$.

$$
T_u\ [\mathrm{s}] \approx \frac{2 · \sum \Delta t_{\mathrm{half}}}{n_{\mathrm{half}} - 1}
$$

Se suman las duraciones de cada semiperiodo (`s_half_sum_s`) y se estima el periodo completo. El primer tramo no entra en la suma (`if (s_half_n > 0)` antes de acumular), coherente con descartar el transient.

Mismo fragmento: cálculo de `tu_s` justo antes de `finish_ok` (líneas 179–182 arriba).

#### Paso 3 — Ganancia límite ($K_u$)

**Qué responde:** “Si el relé al 100 % produce oscilación de amplitud $A$, ¿cuál es la ganancia que pondría al lazo justo en el borde de la estabilidad?”  
Fórmula clásica del método del relé, con $d = 100\,\%$ y escala ×10 del firmware:

$$
K_{u,x10} = \frac{4 · 100 · 10}{\pi · A} \approx \frac{12732}{A}
$$

(resultado limitado a 1…999)

```94:109:firmware/avr/src/services/pid_atune.c
static void finish_ok(app_state_t *st, uint16_t tu_s, int16_t amp)
{
    int32_t ku, kp, ki, tu10;

    if (amp < 5)
        amp = 5;
    ku = 12732L / (int32_t)amp;
    if (ku < 1)
        ku = 1;
    if (ku > 999)
        ku = 999;
    if (tu_s < 1u)
        tu_s = 1u;
    tu10 = (int32_t)tu_s * 10L;
    if (tu10 < 10)
        tu10 = 10;
```

#### Paso 4 — De $K_u$ y $T_u$ a ganancias PI (Ziegler–Nichols)

**Qué responde:** “Con esa ganancia límite y ese periodo, ¿qué Kp y Ki usar en el lazo de trabajo?”  
Regla **PI** del método 2 (lazo cerrado):

$$
K_p = 0{,}45 · K_u,\qquad
T_i = \frac{T_u}{1{,}2},\qquad
K_d = 0
$$

En enteros, Kp ×10 y Ki ×100 (lo que realmente guarda HotPlate):

$$
K_{p,x10} = \mathrm{clip}\big(\lfloor K_{u,x10} · 45 / 100 \rfloor,\ 1,\ 999\big)
$$

$$
K_{i,x100} = \mathrm{clip}\big(\lfloor K_{p,x10} · 120 / (T_u · 10) \rfloor,\ 0,\ 999\big)
$$

porque $K_i = K_p / T_i = K_p · 1{,}2 / T_u$. El factor ×100 de Ki
compensa el ×10 de Kp y `tu10 = T_u · 10`.

```111:124:firmware/avr/src/services/pid_atune.c
    /* Z–N PI (método 2): Kp=0.45 Ku, Ti=Tu/1.2, Kd=0 */
    kp = (ku * 45L) / 100L;
    if (kp < 1)
        kp = 1;
    if (kp > 999)
        kp = 999;
    ki = (kp * 120L) / tu10;
    if (ki < 0)
        ki = 0;
    if (ki > 999)
        ki = 999;

    s_kp = (int16_t)kp;
    s_ki = (int16_t)ki;
```

**Por qué no PID completo:** $T_d = T_u / 8$ en plantas lentas satura el techo ×10 (999) y empeora el lazo. HotPlate usa PI + lookahead en su lugar.

**Resumen del encadenamiento:** medir picos → $A$ · medir tiempos → $T_u$ · $A$ → $K_u$ · $K_u$+$T_u$ → $K_p$, $K_i$ → quedan en `s_kp` / `s_ki` y, al terminar, se copian a EEPROM. No hay `AT+CFG=A`.

### 4.5 Cómo se aplica

- Al terminar, `s_kp` / `s_ki` se copian a `pid_kp_x10` / `pid_ki_x10` y a EEPROM. No hay `AT+CFG=A`.
- Durante el autoajuste el PI de trabajo **no** manda; manda el relé.
- El fan en el medio-ciclo OFF es **independiente** del aire de enfriamiento de HEAT.

### 4.6 Telemetría mínima para portar

| Campo | Uso |
|---|-----|
| Fase | IDLE / RUN / DONE / FAIL |
| Ciclos cerrados | Progreso |
| AK / AI | Kp ×10 / Ki ×100 resultado |

En este producto esos campos van en el mismo `$HP` (`AP`, `AC`, `AK`, `AI`), no en una trama aparte. El `$HP` sale a 1 Hz durante toda la sesión USB y lleva esos campos mientras `ATUNE_RUN` (más la trama de DONE/FAIL). Baud y activación: [usb-automation.md](usb-automation.md).

---

## 5. Checklist para llevarlo a otro MCU / proyecto

1. Sensor periódico (1 s, o escala $R$ y `rate` al `dt` real).
2. Actuador con duty 0…100 % (SSR o PWM equivalente).
3. Copiar gobernador + lookahead + PI + anti-windup + ventana.
4. En cada cambio de SET del Soldering Profile: equivalente a `pid_on_set_step`.
5. Autoajuste opcional: relé + Z–N PI; no mezclar con el PI durante la identificación.
6. Seguridad: cortar calor si $T ≥ T_{\max}$.
7. Validar en banco: subida, meseta dentro de banda, overshoot dentro de tolerancia.

### Pseudocódigo mínimo (lazo)

```
each sample:
  rate = T - T_prev
  if t_ref < SET*10: t_ref = min(SET*10, t_ref + RISE)
  else: t_ref = SET*10
  Tpred = T + clamp(rate * LOOKAHEAD, ±5000)
  e = t_ref - Tpred
  if sample_count % 10 == 0 and not saturated_favor(duty, e):
      I10 = clamp(I10 + e, ±1000)
  u = clamp((Kp_x10*e + Ki_x100*I10)/10, 0, 1000)
  duty = u / 10
each loop:
  apply time_proportioning(duty, WINDOW_MS) to heater
```

---

## 6. Mapa a este repositorio

| Concepto | Archivo / símbolo |
|---|---|
| Lazo | `src/services/pid.c` |
| Autoajuste | `src/services/pid_atune.c` |
| RISE, LOOKAHEAD, WINDOW | `src/app/app_config.h` |
| Kp/Ki EEPROM | `cfg_store` + `AT+CFG=P` / `A` |
| Fases que llaman al PI | `program_runner` → `pid_tick` |
| Skill agente | `.cursor/skills/hotplate-pid/SKILL.md` |
| Guardián flash | `.cursor/skills/hotplate-feature-budget/SKILL.md` · `feature_budget.md` |

---

## 7. Uso del conocimiento

Algoritmo del proyecto **SMI HotPlate**.  
Autoría: **Crhistian David Vergara Gómez** · krisskira@gmail.com.

Puedes reutilizar las **fórmulas y el procedimiento** en otros proyectos; adapta actuador/sensor y vuelve a validar en banco.

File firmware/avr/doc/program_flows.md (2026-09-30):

# Flujos de HotPlate — HEAT, PREHEAT, control y autoajuste

Documento **maestro** del orden de fases, actuadores, memoria y alarmas.  
Si otro archivo discrepa en el comportamiento térmico, **manda este**.

| También ver | Para |
|---|---|
| [architecture.md](architecture.md) | Cómo está organizado el firmware |
| [usb-automation.md](usb-automation.md) | Comandos AT y tramas `$HP` / `$CF` / `$R` |
| [pid_control.md](pid_control.md) | Fórmulas del PI predictivo y del autoajuste |
| [product_features.md](product_features.md) | Visión de producto (HotPlate, HotPanel, Soldering Profile) y mapa doc↔código |

Última actualización: **2026-09-29**. Formato EEPROM global **v8**.

---

## Qué mueve HotPlate

| Actuador | Hardware | En código | Quién lo manda |
|---|---|---|---|
| Banco calefactor (PTC1+PTC2) | Micro → opto **MOC3021** → triac **BT136** (SSR; no es relé mecánico) | `outputs_bank_set` / ventana PID | Lazo PI, autoajuste, precalentamiento |
| Aire (ventilador / bomba) | Fan | `fan_on` / `fan_off` | Fin de HEAT (`PH_ALARM` / `PH_COOLDOWN` si el aire asistido está activo); en autoajuste, solo en el medio-ciclo OFF |
| Avisos | Buzzer piezo | `buzzer_seq_beep_cat` | Navegación, confirmación, listo, alarma |

BOM y datasheets: `hardware/pcb/` y `hardware/datasheets/`.

---

## Qué se guarda y qué solo vive en marcha

Algunos datos viven en **EEPROM** (sobreviven al apagado). Otros solo existen **mientras corre** el ciclo (RAM + telemetría).

| Dato | En EEPROM (v8) | En RAM (`app_state_t`) | Notas |
|---|---|---|---|
| Ganancias Kp ×10 / Ki ×100 | sí | `pid_kp/ki_x10` (nombre de Ki heredado) | Tras autoajuste o edición (sin Kd) |
| Ciclos objetivo del autoajuste | sí | `atune_cycles_target` | Default **5** |
| Histéresis del autoajuste | sí | `atune_hyst_c_x10` | Ancho del “relé” alrededor del SET |
| Tiempo máximo del autoajuste | sí | `atune_max_s` | 120…3600 s; default **2000** |
| Temperatura mínima / máxima | sí | `temp_min_c` / `temp_max_c` | Piso de consignas + corte de seguridad |
| Precalentamiento on/off | sí | `preheat_en` | Si es 0, HEAT salta PREHEAT y STABILIZE |
| % de precalentamiento | sí | `preheat_pct` | 50…100; default **80** (% de la rampa 1) |
| Soldering Profile (rampas) | bloque `ee_ramp` | `ramp_n`, `ramp_step[]` | No es un programa lanzable |
| Retraso de HEAT | `ee_heat` (`uint16`: hora en el byte alto, minuto en el bajo; `flags` bit0 marca este formato) | `delay_h` + `delay_m` | **00:00** = arranque inmediato. Tope **12:00**. Un valor antiguo en segundos (sin ese bit) se convierte al leerlo |
| SET del autoajuste | `ee_tune` | `t_set_c` | Centro de oscilación (`AT+RUN=2`) |

La fase viva (`phase`, tiempo restante, índice de rampa, duty…) solo está en RAM y en la trama `$HP`.  
Los picos y las ganancias resultado del autoajuste viven en estáticos de `pid_atune` (el algoritmo los usa; `$HP` los lee). No van en `app_state` y **no hay** buffer de traza en el equipo.

---

## Alarmas y pitidos

Los pitidos no se definen como “una nota de X Hz”. Cada evento usa una **categoría**: la categoría fija el ancho del pulso; el número indica cuántas veces se repite (ON → pausa OFF → ON…).

| Categoría | Pulso | Cuándo |
|---|---|---|
| `CONFIRM` | 30 ms ON / 60 ms OFF, 1 vez | HotPanel guardó un valor (rampa, meseta o retraso) en EEPROM |
| `READY` | 50 ms ON / 80 ms OFF, mínimo 3 | Fin de ciclo / aviso de alarma |
| `ALARM` | 50 ms ON / 80 ms OFF | Arranque rechazado (sin rampas o fallo). No se silencia |

No hay pitido de navegación, ni al arrancar, parar o salir de USB.

| Qué ocurre | Por USB | Pitido | Campo `$HP` ACTION | Notas |
|---|---|---|---|---|
| HEAT termina las rampas | línea `ALARM:2` | `READY`: 3 pulsos | `ALARM` | Calefactor OFF; aire si está activado. Mientras dura `PH_ALARM`, el mismo `READY` se repite cada `alarm_period_s` |
| Sobretemperatura | `ERROR:7` | ninguno | `FAULT` | Lectura válida ≥ `temp_max_c` → PTC OFF, fase `PH_FAULT` |
| Consigna inalcanzable | `ERROR:9` | ninguno | `FAULT` | 180 s en `PH_RUN` con duty ≥ 95 %, pendiente ≤ 0,2 °C/s y T bajo la banda |
| Cambio de fase | sin línea aparte | ver abajo | token de la fase nueva | El token va **dentro** de `$HP` |
| Abort desde HotPanel en vista USB | `ERROR:8` | ninguno | — | Todo OFF → HOME |

**Cuándo pitan los cambios de fase**

- Entrar en meseta (`HOLD`) o en terminado (`DONE`): `READY` (3 pulsos).
- Entrar en `ALARM`: el mismo `READY` al instante (no espera al tick de 1 s) y luego cada `alarm_period_s`.
- Espera, precalentamiento, estabilización, subida y enfriamiento **no** pitan.

Tokens de `$HP` ACTION: `WAITING`, `PREHEATING`, `STABILIZING`, `RUNNING`, `COOLING`, `DONE`, `TUNING`, `ALARM`, `FAULT`, `IDLE`.

**Cancelar vs. reconocer el fin**

| Acción | Efecto |
|---|---|
| Confirmar en HotPanel / `AT+STOP` durante `PH_ALARM` | Cierra la alarma; HEAT puede pasar a enfriamiento |
| **Cancelar** en HotPanel durante espera / precalentamiento / rampas | Abort seco → `PH_IDLE` (**sin** `ALARM:2`) |
| `AT+STOP` por USB en esas mismas fases | Se trata como fin de ciclo → `PH_ALARM` + `ALARM:2` |

---

## HEAT — el ciclo del Soldering Profile

Se lanza desde **HotPanel** (casilla Heat) o por USB (`AT+RUN=1`).

En esa casilla, HotPanel mantiene la temperatura a 2×, la fase y la fila `Rx T°C` con el tiempo de la etapa. Debajo, centrado, cuenta `mm:ss` desde el arranque (`t_elapsed_s`; `00:00` en reposo). El overlay USB no pinta fase, perfil ni ese contador.

### Qué necesita para arrancar

- Reloj de retraso `00:00`…`12:00` (`delay_h`, `delay_m`): si no es `00:00`, primero cuenta atrás **sin calor**
- Soldering Profile con al menos una rampa (`ramp_n` ≥ 1): temperatura y `hold_s` por escalón
- Ganancias PI, límites `temp_min_c` / `temp_max_c`, y si el aire asistido está activo

### Camino completo

```mermaid
flowchart TD
  start([Inicio HEAT]) --> dly{"¿retraso > 00:00?"}
  dly -->|sí| wait[Espera · calefactor OFF]
  dly -->|no| r1["Subida rampa 1 · PI a su temperatura"]
  wait -->|cuenta a 0| r1
  r1 --> band{"¿T en banda del SET?"}
  band -->|no| r1
  band -->|sí| h1["Meseta · hold_s + PI"]
  h1 --> more{¿Más rampas?}
  more -->|sí| rn["Subida Ramp i · PI"]
  rn --> band2{"¿T en banda?"}
  band2 -->|sí| hn["Meseta · hold_s"]
  hn --> more
  more -->|no| alrm["Aviso de fin · ALARM:2"]
  alrm --> cool{"¿Aire y T > temp_min?"}
  cool -->|sí| cd["Enfriamiento · fan ON"]
  cool -->|no| done(["Listo · todo OFF"])
  cd -->|T ≤ temp_min| done
```

### Qué hace cada fase

| Fase | Calefactor (SSR) | Aire | Cuándo avanza |
|---|---|---|---|
| Espera (`DELAY`) | OFF | OFF | Cuando el contador llega a 0 |
| Subida (`RUN`, rampa i) | PI al SET del escalón (referencia `t_ref` + anticipación; al entrar se alinea `t_ref` a T) | OFF | Approach controlado: **aún no** cuenta `hold_s`. Al entrar en ± BN → meseta. Si durante 180 s el duty es ≥ 95 %, la pendiente es ≤ 0,2 °C/s y T sigue bajo la banda, `ERROR:9` y `FAULT` (el SET no se alcanza). La rampa 1 es el primer escalón |
| Meseta (`HOLD`, rampa i) | PI mantiene el SET | OFF | Aquí sí corre `hold_s`. Al agotarse → siguiente rampa o fin. El Soldering Profile **no puede bajar** de rampa a rampa (`ERROR:2` si lo intenta) |
| Aviso de fin (`ALARM`) | OFF | ON si el aire asistido está activo | Timeout o confirmación → enfriamiento o listo |
| Enfriamiento (`COOLDOWN`) | OFF | ON | Cuando `T ≤ temp_min_c` → fan OFF y listo |
| Listo (`DONE`) | OFF | OFF | — |

### Soldering Profile

- Las rampas **no** se lanzan solas: forman el Soldering Profile que HEAT recorre, empezando por la rampa 1 a su temperatura.
- No hay una fase previa al porcentaje de la rampa 1. RSS, rampa a pico, reflow o soldadura son el mismo HEAT con más o menos escalones.
- La meseta no se aborta si la temperatura se sale de `BX`. `BX` se guarda; quien decide el paso a meseta es `BN`.

### Retraso desde HotPanel

El retraso se edita en **Ajustes → DLY** como reloj `hh:mm` (pulsar: horas, luego minutos; tope 12:00). En la casilla Heat, un PRESS arranca HEAT; el retraso no se edita ahí. En EEPROM cabe en el `uint16` de `ee_heat`: byte alto = horas, byte bajo = minutos. La cuenta atrás usa esos dos bytes más un contador de 0…59 s, sin guardar las 12 h en segundos.

---

## Rampa 1

No es un programa aparte ni una casilla de HotPanel.  
Es el primer escalón del Soldering Profile: su temperatura y su `hold_s`. No hay `AT+RUN` propio ni cálculo de porcentaje.

---

## Control de temperatura (lazo PI)

Guía completa (variables, fórmulas, tuning, portabilidad): **[pid_control.md](pid_control.md)**.

En pocas palabras:

- La potencia se aplica por **ventanas** (`PID_WINDOW_MS`): el % de duty es cuánto tiempo el SSR está ON dentro de cada ventana.
- Activo en precalentamiento, estabilización, subida y meseta.
- **PI predictivo:** una referencia interna sube hacia el SET a ritmo limitado (`RISE_C_X10_DEFAULT`, p. ej. 1,2 °C/s) y el error mira un poco al futuro (`LOOKAHEAD_S_DEFAULT`, p. ej. 15 s) para cortar antes por inercia. Sin término D (Kd = 0).
- Anti-windup: no integra si el duty ya está saturado a favor del error. Entre rampas **no** se borra el integral; al cambiar de SET se llama `pid_on_set_step` (tasa = 0, `t_ref ← T`) para no heredar la “cola” del precalentamiento.
- Kp/Ki viven en EEPROM (`AT+CFG=P`). HotPanel no edita el PID. `rise` / `lookahead` son de compilación (ahorro de flash). `$CF` no emite `KD` (siempre 0).

---

## Autoajuste (`PID_TUNE`)

Detalle matemático: **[pid_control.md](pid_control.md)** § Autotune.

Solo por USB (HotPlate Studio / AT). HotPanel **no** lo lanza.

1. Opcional: guardar parámetros sin arrancar → `AT+CFG=T,ciclos,hyst,max_s`.
2. Arrancar → `AT+RUN=2,temp,ciclos,hyst[,max_s]`.
3. HotPlate oscila todo/nada alrededor del SET (histéresis `atune_hyst_c_x10`) durante `atune_cycles_target` ciclos.
4. Mide amplitud y periodo → calcula \(K_u\) y \(T_u\) → regla **Ziegler–Nichols PI** (\(K_p=0.45K_u\), \(T_i=T_u/1.2\), \(K_d=0\)).
5. Al terminar, Kp/Ki se copian solos a EEPROM. No hay `AT+CFG=A`.

Si se pasa de `atune_max_s` → fallo (default **2000** s; `$CF AMS=`).

Durante el medio-ciclo OFF el ventilador ayuda a bajar más rápido (protege SMD del tiempo encima de consigna). Eso es independiente del aire al final de HEAT.

| Origen | Qué se publica |
|---|---|
| USB | El `$HP` de sesión (1 Hz) suma progreso (`AP`, `AC`) y ganancias (`AK`, `AI`); la trama de DONE o FAIL es la última con esos campos. Sin segundo emisor ([usb-automation.md](usb-automation.md)) |
| HotPanel | No lanza autoajuste ni dibuja la curva |

No hay trama `$HP,PLOT`. La banda de oscilación es `t_set ± histéresis`.

| Momento del autoajuste | Calefactor | Aire | `$HP` ACTION |
|---|---|---|---|
| Medio-ciclo ON | ON | OFF | `TUNING` |
| Medio-ciclo OFF | OFF | ON | `TUNING` |
| DONE / FAIL | OFF | OFF | — |

Cancelar (STOP / fault) quita `AP,AC,AK,AI`; el `$HP` de estado sigue a 1 Hz mientras USB permanezca abierto. El siguiente `RUN=2` pone a cero las ganancias resultado hasta el nuevo DONE.

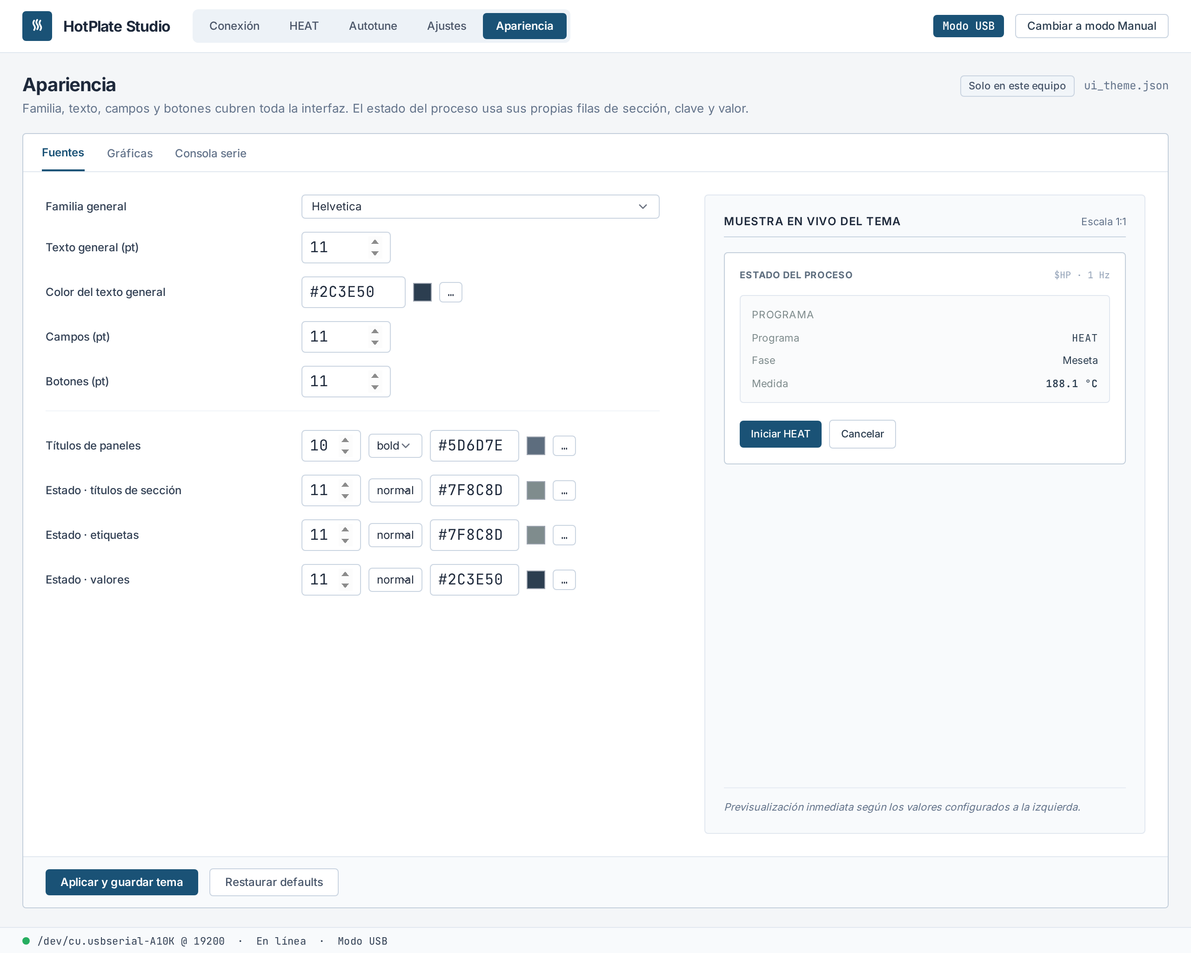
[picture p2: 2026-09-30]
hotplate-studio/design/stitch/apariencia-fuentes.png

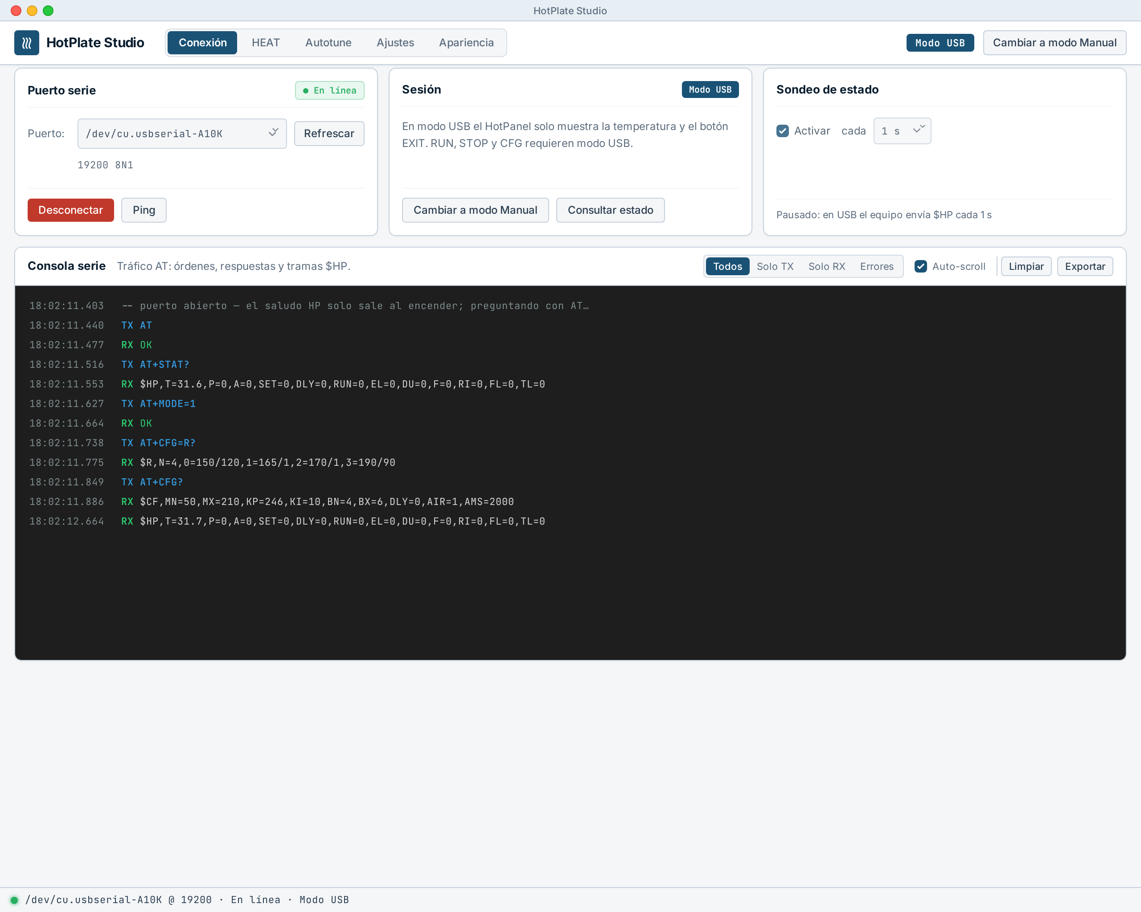
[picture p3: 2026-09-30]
hotplate-studio/design/stitch/conexion.png

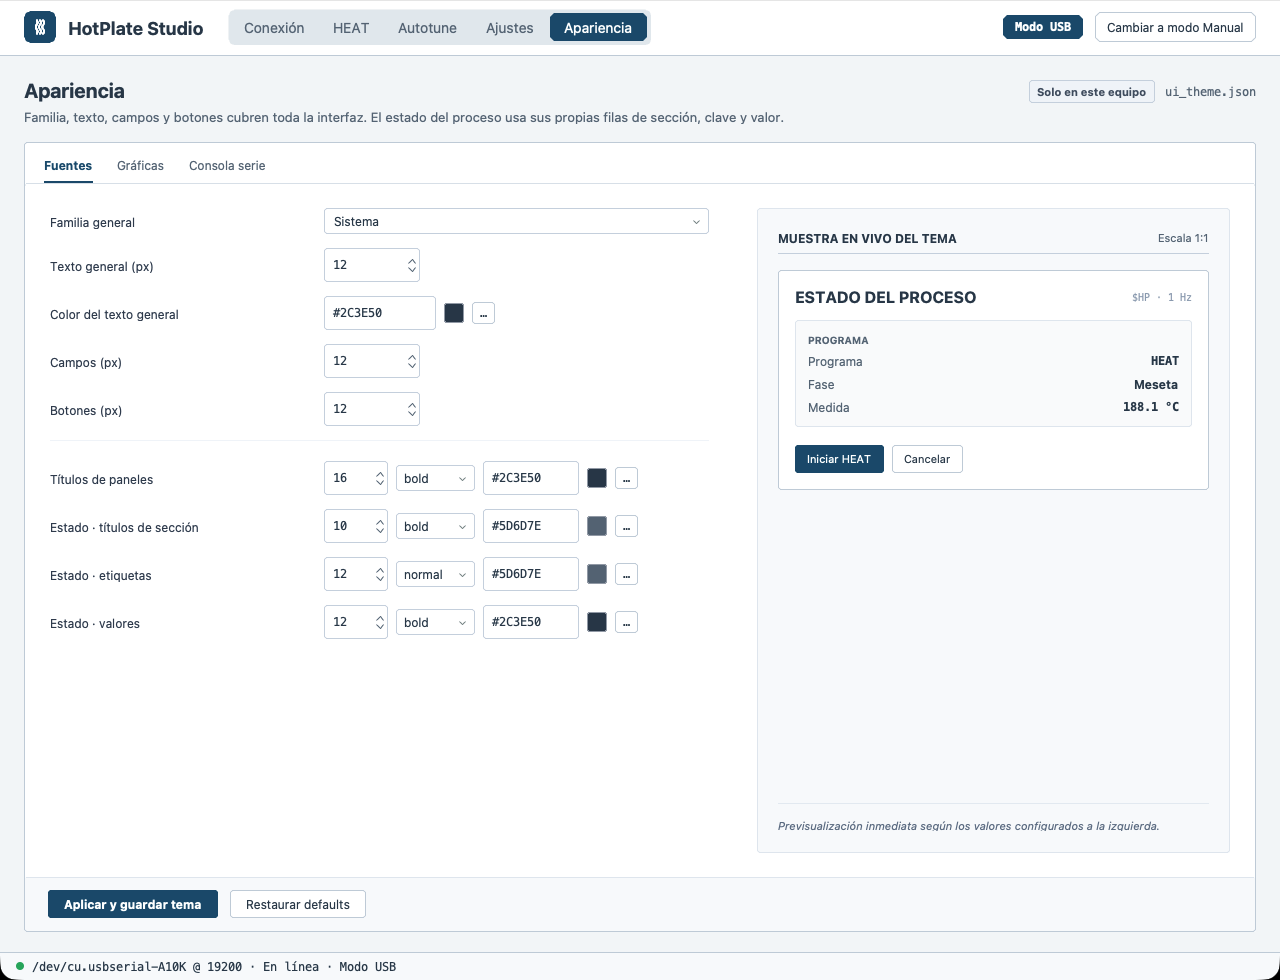
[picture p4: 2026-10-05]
hotplate-studio/design/previews/07_apariencia.png

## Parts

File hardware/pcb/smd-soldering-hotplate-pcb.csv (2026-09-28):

Reference | Qty | Value | DNP | Exclude from BOM | Exclude from Board | Footprint | Datasheet
BZ1 | 1 | Buzzer |  |  |  | Buzzer_Beeper:Buzzer_12x9.5RM7.6 | ~
C1 | C2 | 2 | 27pf |  |  |  | Capacitor_THT:C_Disc_D5.0mm_W2.5mm_P2.50mm | ~
C3 | C4 | 2 | 100nf |  |  |  | Capacitor_THT:C_Rect_L10.3mm_W5.0mm_P7.50mm_MKS4 | ~
C5 | C6 | 2 | 0.1uF |  |  |  | Capacitor_THT:C_Disc_D5.0mm_W2.5mm_P2.50mm | ~
C7 | 1 | 100nF |  |  |  | Capacitor_THT:C_Disc_D5.0mm_W2.5mm_P2.50mm | ~
D1 | D2 | 2 | SS14 |  |  |  | Diode_SMD:D_SMA | https://www.vishay.com/docs/88746/ss12.pdf
D3 | 1 | 1N4004 |  |  |  | Diode_THT:D_DO-41_SOD81_P10.16mm_Horizontal | http://www.vishay.com/docs/88503/1n4001.pdf
FAN1 | H_POWER1 | PTC1 | PTC2 | 4 | Screw_Terminal_01x02 |  |  |  | TerminalBlock:TerminalBlock_MaiXu_MX126-5.0-02P_1x02_P5.00mm | ~
ISP1 | 1 | Conn_02x05_Odd_Even |  |  |  | Connector_PinHeader_2.54mm:PinHeader_2x05_P2.54mm_Vertical | ~
J4 | 1 | USB_A |  |  |  | Connector_USB:USB_A_TE_292303-7_Horizontal | ~
LCD1 | 1 | ST7920-12864B |  |  |  | st7920-12864b-v2:st7920-12864b-v2 | https://dfimg.dfrobot.com/enshop/image/data/FIT0021/ST7920.pdf
Menu1 | 1 | RotaryEncoder_Switch |  |  |  | Rotary_Encoder:RotaryEncoder_Alps_EC11E-Switch_Vertical_H20mm | ~
POWER_CONTROL_1 | POWER_CONTROL_2 | 2 | Conn_01x05_Pin |  |  |  | Connector_Molex:Molex_KK-254_AE-6410-05A_1x05_P2.54mm_Vertical | ~
PS1 | 1 | HLK-PM01 |  |  |  | Converter_ACDC:Converter_ACDC_Hi-Link_HLK-PMxx | https://h.hlktech.com/download/ACDC%E7%94%B5%E6%BA%90%E6%A8%A1%E5%9D%973W%E7%B3%BB%E5%88%97/1/%E6%B5%B7%E5%87%8C%E7%A7%913W%E7%B3%BB%E5%88%97%E7%94%B5%E6%BA%9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
Q1 | Q2 | 2 | BT136-600 |  |  |  | Package_TO_SOT_THT:TO-220-3_Vertical | http://www.micropik.com/PDF/BT136-600.pdf
Q3 | 1 | 2N2222 |  |  |  | Package_TO_SOT_THT:TO-92_Inline | https://www.onsemi.com/pub/Collateral/2N3903-D.PDF
R1 | R4 | R11 | R12 | R13 | R14 | 6 | 10K |  |  |  | Resistor_THT:R_Axial_DIN0309_L9.0mm_D3.2mm_P12.70mm_Horizontal | ~
R2 | R3 | 2 | 330 |  |  |  | Resistor_THT:R_Axial_DIN0309_L9.0mm_D3.2mm_P12.70mm_Horizontal | ~
R5 | R6 | 2 | 220 |  |  |  | Resistor_THT:R_Axial_DIN0309_L9.0mm_D3.2mm_P12.70mm_Horizontal | ~
R7 | R8 | R9 | R10 | 4 | 100 |  |  |  | Resistor_THT:R_Axial_DIN0414_L11.9mm_D4.5mm_P15.24mm_Horizontal | ~
SW1 | 1 | SW_Push_Dual_x2 |  |  |  | Button_Switch_THT:SW_PUSH_6mm_H5mm | ~
TEMPERATURE_CONTROL1 | 1 | Max31865 |  |  |  | Connector_PinHeader_2.54mm:PinHeader_1x08_P2.54mm_Vertical | ~
U1 | 1 | ATmega16L-8P |  |  |  | Package_DIP:DIP-40_W15.24mm | http://ww1.microchip.com/downloads/en/DeviceDoc/doc2466.pdf
U2 | U3 | 2 | MOC3021M |  |  |  | Package_DIP:DIP-6_W7.62mm | https://www.onsemi.com/pub/Collateral/MOC3023M-D.PDF
U4 | 1 | CH340C |  |  |  | Package_SO:SOIC-16_3.9x9.9mm_P1.27mm | https://datasheet.lcsc.com/szlcsc/Jiangsu-Qin-Heng-CH340C_C84681.pdf
Y1 | 1 | 16Mhz |  |  |  | Crystal:Crystal_HC49-4H_Vertical | ~

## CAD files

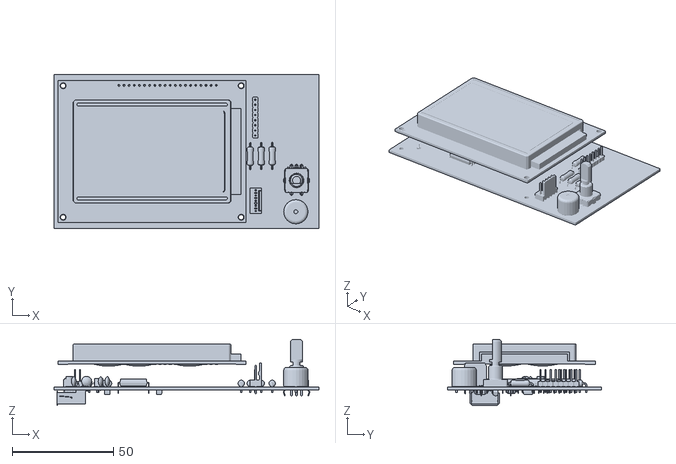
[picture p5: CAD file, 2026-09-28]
hardware/pcb/controller.stl
131.0 x 76.0 x 32.8

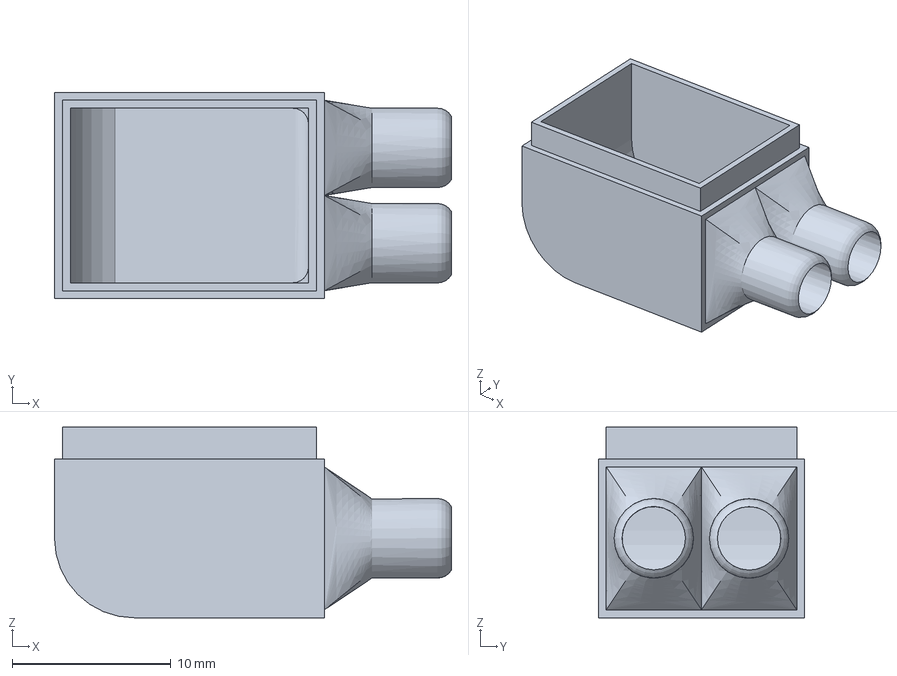
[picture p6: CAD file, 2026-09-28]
mechanical/air-flower.3mf
25.0 x 13.0 x 12.0 mm

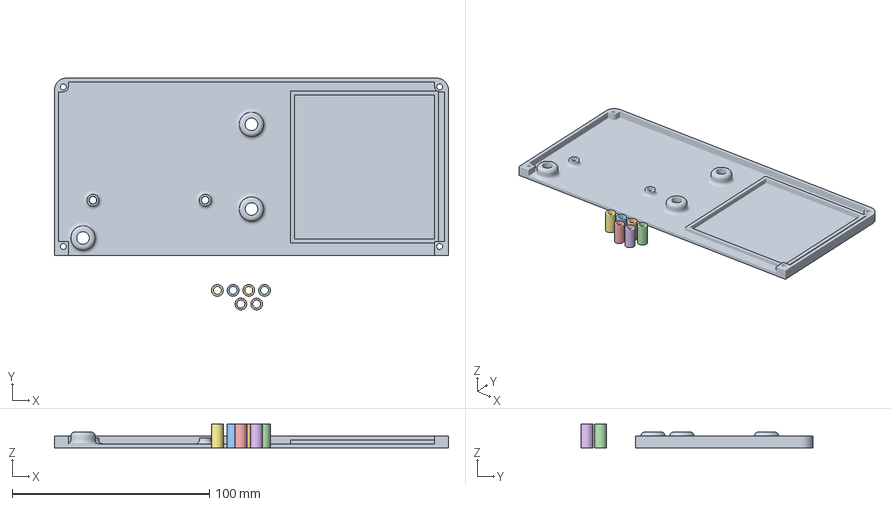
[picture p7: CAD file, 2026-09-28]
mechanical/hotplate-INFERIOR.3mf
200.0 x 117.7 x 12.0 mm

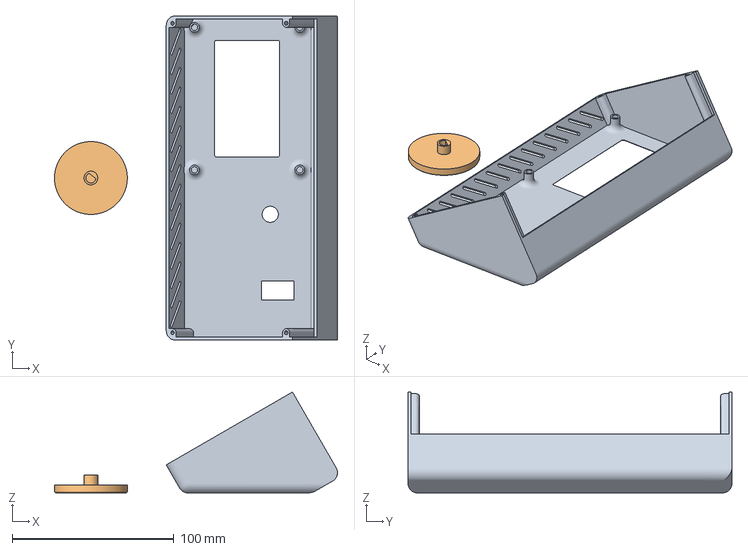
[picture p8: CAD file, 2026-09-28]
mechanical/Hotplate.3mf
174.7 x 200.0 x 62.3 mm
Carcasa
perilla

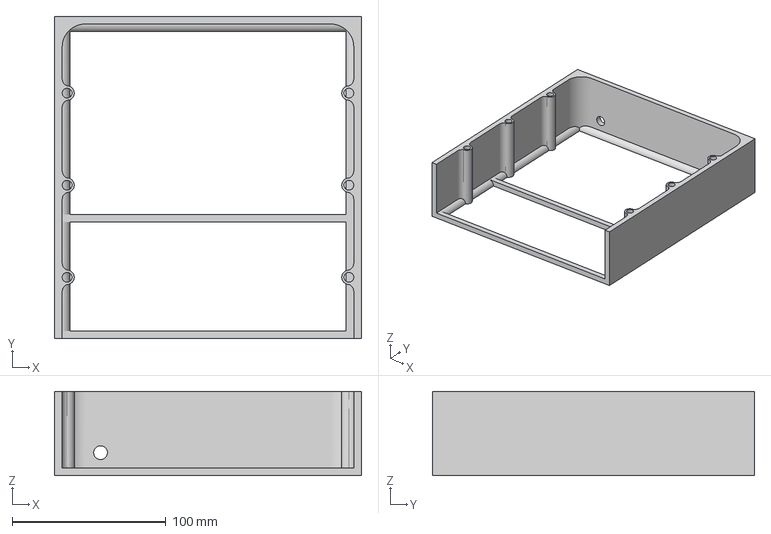
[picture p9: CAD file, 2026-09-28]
mechanical/Hotplate-Tapa-trasera.3mf
200.0 x 210.0 x 55.0 mm

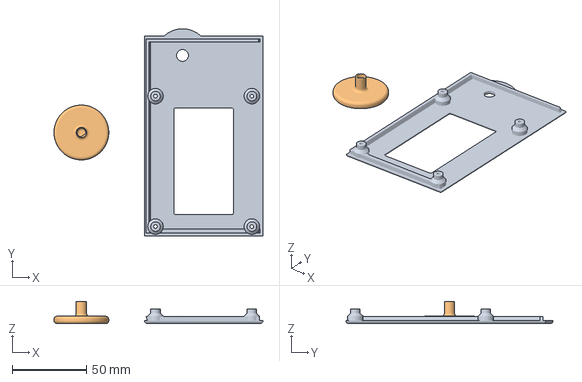
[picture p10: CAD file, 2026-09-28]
mechanical/Case.3mf
141.0 x 139.9 x 15.0 mm
Tapa
Selector

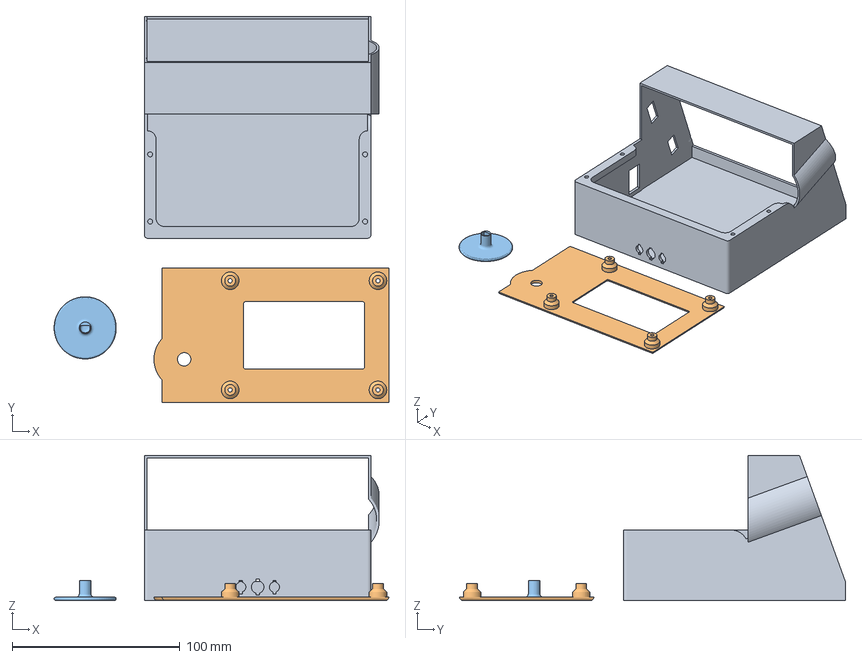
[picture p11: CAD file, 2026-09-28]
mechanical/SolderingHotPlateCase.3mf
199.4 x 229.8 x 86.4 mm
Sides
Tapa
Selector

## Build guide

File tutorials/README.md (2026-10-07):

# Tutoriales de HotPlate

Paquete para la sección de tutoriales de kriver-device. Cubre el hardware, el firmware y HotPlate Studio con el material real del proyecto: fotos del equipo, el fresado de la PCB, el modelo 3D, las pantallas de la LCD y las capturas de Studio.

Cada video es MP4, 1920×1080, sin voz. La narración va en subtítulos quemados y, además, en un `.srt` al lado del archivo para poder ofrecerlos como pista aparte.

| Pieza | Vídeo | De qué habla |
|---|---|---|
| Promo | `videos/promo.mp4` | El producto de punta a punta, en un minuto |
| 01 | `videos/01-pcb.mp4` | Fresado de la PCB en cobre |
| 02 | `videos/02-modelado-3d.mp4` | Carcasa en Fusion 360 e impresión |
| 03 | `videos/03-firmware.mp4` | Firmware y estados de HotPanel |
| 04 | `videos/04-hotplate-studio.mp4` | Cómo está hecha la aplicación |
| 05 | `videos/05-calibracion.mp4` | Límites, bandas, autoajuste y un ciclo de prueba |

El texto largo de cada pieza está en su carpeta (`01-pcb/tutorial.md`, etc.). Las imágenes de apoyo están en `referencias/`. El índice para montar la sección está en `manifest.json`.

La música es CC0 y está copiada en `audio/`. Créditos en `CREDITOS.md`.

Para regenerar los vídeos (hace falta el material de `~/Downloads/fotos-hotplate` y ffmpeg):

```bash
python3 tutorials/build_videos.py
```

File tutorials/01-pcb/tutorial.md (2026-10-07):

# Fabricar la PCB

La placa de HotPlate no sale de un proceso químico. Se fresa en cobre, en una CNC de escritorio, a partir del plano de KiCad que está en `hardware/pcb/`. El mismo cobre lleva la lógica de control y la etapa de potencia.

## Qué se ve en el taller

La fresa recorre el cobre y deja un surco que aísla cada pista. El plano manda el recorrido: pads redondos, uniones y el contorno de la placa. Cuando la máquina termina, el cobre que no es pista sigue ahí, separado por ese surco. No hay máscara verde ni serigrafía de fábrica; la revisión se hace a ojo y con el microscopio USB, buscando un corte que abra una pista o un puente que una dos redes.

En las fotos de referencia se ve la CNC con la placa sujeta, el detalle de la fresa sobre el cobre, las pistas ya aisladas y la imagen del microscopio.

## Qué lleva esa placa

El plano junta las piezas que el firmware necesita para cerrar el ciclo:

- ATmega16 a 8 MHz, que lee, decide, dibuja la pantalla y atiende el USB.
- MAX31865 y la PT100, para la temperatura.
- MOC3021 y BT136, el relé de estado sólido que enciende las dos resistencias PTC.
- Conector de la ST7920 128×64, el encoder y el buzzer.
- La salida de la bomba de aire, que sopla al final del ciclo.

El fresado deja el cobre listo para soldar esos componentes. Hasta que no están puestos y el sensor responde, el equipo arranca con las salidas apagadas: un fallo de sensor o pasar la temperatura máxima corta el calor.

## Material de esta pieza

- Vídeo: `videos/01-pcb.mp4` y `videos/01-pcb.srt`
- Fotos: `referencias/01-pcb/`

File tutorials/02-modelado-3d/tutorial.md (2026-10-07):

# Modelar e imprimir la carcasa

La electrónica cabe en una caja que se modela antes de imprimir. Los archivos viven en `mechanical/`: carcasa, base inferior, tapa trasera, tapa con perilla y el difusor de aire. El origen es Fusion 360; lo que se imprime son los 3MF exportados.

## Qué resuelve el modelo

El frente va inclinado para mirar la pantalla y girar la perilla sin levantar la placa caliente. En el modelo se reservan el hueco de la LCD, el eje del encoder y el interruptor. La placa de aluminio no apoya en el plástico: cuatro postes la separan de la caja, de modo que el calor se queda en el aluminio y la carcasa no es la superficie de trabajo.

El lateral impreso lleva un relieve que repite el dibujo de las pistas. No es un adorno suelto: es la misma geometría del proyecto, pasada a la pared de la caja. La perilla se imprime aparte y se monta sobre el encoder.

## Del modelo al equipo cerrado

En la foto de banco se ven las dos cosas a la vez: el sólido abierto en el monitor, con el frente, la ventana y los apoyos, y debajo el equipo ya montado, con la placa de aluminio, los postes y la pantalla encendida. Esa foto es la referencia de que el impreso sigue al modelo, no al revés.

Cuando la caja cierra, el conjunto queda así: aluminio arriba, frente claro con la textura de la impresión, lateral oscuro con el relieve, perilla negra e interruptor. A partir de ahí el calor lo decide el firmware, no la forma de la caja.

## Material de esta pieza

- Vídeo: `videos/02-modelado-3d.mp4` y `videos/02-modelado-3d.srt`
- Fotos: `referencias/02-modelado/`

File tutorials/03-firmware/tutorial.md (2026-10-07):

# El firmware en el ATmega16

El firmware está en C, sin sistema operativo, compilado con avr-gcc. Corre en un ATmega16 a 8 MHz y cabe en los 16 KB de flash. Un planificador cooperativo reparte el tiempo: leer la PT100, calcular la potencia, avanzar el perfil, refrescar la ST7920 y atender la UART. Nada de eso se queda bloqueado esperando.

## Lo que hace un ciclo HEAT

Hay dos programas. HEAT es el ciclo de soldadura. El autoajuste es el otro, y solo se lanza desde el computador. HEAT recorre un perfil de hasta cuatro escalones. Cada escalón tiene temperatura y tiempo de meseta. Los escalones solo suben o se mantienen: un perfil que baja se rechaza antes de arrancar.

El orden, una vez pulsas RUN, es fijo. Si hay espera (`00:00` es inmediato, el tope es 12 horas), cuenta atrás. Luego sube el escalón 1, sostiene su meseta, y sigue con el 2, el 3 y el 4. Al terminar apaga el calor, pita y, si está pedido, enciende el aire hasta la temperatura mínima.

La pantalla lo cuenta en grande. En reposo espera. En espera programada muestra la cuenta. En RUN se ve la temperatura, el escalón, la consigna y el tiempo. En meseta corre el reloj de esa etapa. Al acabar, el aviso. Si Studio toma el mando, la pantalla pasa a USB y la perilla deja de actuar. Nunca hay dos mandos a la vez.

## Cómo regula el calor

La placa tiene inercia. Si se corta la potencia al llegar a la consigna, la temperatura sigue subiendo. El lazo es un PI predictivo: mira hacia adelante y recorta potencia antes. No hay término derivativo. La salida no es un PWM fino del triac a oído: es el tiempo de encendido del relé de estado sólido dentro de una ventana fija.

Las ganancias Kp y Ki viven en la EEPROM, junto con el perfil y los límites. El autoajuste las recalcula y solo las escribe si el ensayo termina. Un corte a medias no pisa los valores anteriores.

Si el sensor no responde, si se alcanza la temperatura máxima, o si la consigna se queda inalcanzable con la potencia al tope, las salidas se apagan.

## Material de esta pieza

- Vídeo: `videos/03-firmware.mp4` y `videos/03-firmware.srt`
- Pantallas: `referencias/03-firmware/`
- Detalle del lazo: `firmware/avr/doc/pid_control.md`
- Orden del ciclo: `firmware/avr/doc/program_flows.md`

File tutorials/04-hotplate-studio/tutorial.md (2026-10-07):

# HotPlate Studio

Studio es la aplicación de escritorio, en Python, con la que el computador maneja el HotPlate. Se abre con `python app.py` dentro de `hotplate-studio/`. En macOS, `./build.sh` deja un ejecutable. Mientras Studio tiene el mando, HotPanel muestra USB y el encoder no cambia nada.

## Cómo está escrita

La ventana solo dibuja. Un botón no habla con el puerto: pide una acción al controlador, y el controlador manda una orden AT por la UART a 19200 8N1. Hay una sola orden en vuelo. Hasta que llega `OK` o `ERROR`, no sale la siguiente. Una trama `$HP` que aparezca en medio no cuenta como esa respuesta.

Al conectar, la app envía `AT` y toma `OK` como «en línea». El saludo `HP` del equipo solo sale al encender, así que abrir el puerto no lo vuelve a ver. Pasar a modo USB es `AT+MODE=1`. Volver a manual es `AT+MODE=0`, el botón EXIT del panel o un reinicio del equipo.

En manual, Studio puede preguntar el estado cada cierto tiempo. En USB no hace falta: el equipo manda solo una trama `$HP` cada segundo, con temperatura, consigna, fase, escalón, potencia y salidas. Al entrar en USB lee el perfil (`$R`) y los ajustes (`$CF`).

Cinco páginas comparten esa sesión: Conexión, HEAT, Autotune, Ajustes y Apariencia. HEAT y Autotune usan el mismo panel de estado y la misma curva. La apariencia (fuentes y colores) se queda en el computador; no se envía al equipo. Las cinco páginas siguen montadas aunque solo se vea una, para que la curva no se congele al cambiar de pestaña.

## Qué guarda y dónde

El perfil que el equipo ejecuta vive en su EEPROM. Studio, además, guarda tres archivos junto al programa: `ramps.json` (el perfil editado en HEAT), `tune_params.json` (los parámetros del autoajuste) y `ui_theme.json` (solo la apariencia local). Guardar rampas envía el perfil al equipo. Leer rampas lo trae de vuelta.

En HEAT se arman hasta cuatro escalones, se lanza o se detiene el ciclo, y se ve la curva: temperatura medida, consigna, potencia y los cambios de fase. El registro se exporta a CSV. Esa curva es la misma historia que HotPanel resume en una línea.

## Material de esta pieza

- Vídeo: `videos/04-hotplate-studio.mp4` y `videos/04-hotplate-studio.srt`
- Capturas: `referencias/04-studio/`
- Arquitectura de la app: `hotplate-studio/ARCHITECTURE.md`
- Protocolo: `firmware/avr/doc/usb-automation.md`

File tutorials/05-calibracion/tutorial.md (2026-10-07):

# Calibrar con HotPlate Studio

Calibrar HotPlate es dejar por escrito los límites, las bandas de meseta y las ganancias del PI, y comprobarlos con un ciclo real. No se hace a ojo en la perilla. Se hace en Studio, con el equipo en línea, y lo que vale queda en la EEPROM.

## 1. Entrar en el equipo

En Conexión se elige el puerto, a 19200 8N1, y se espera `OK` al `AT`. Luego se pasa a modo USB (`AT+MODE=1`). En ese modo la pantalla del equipo muestra USB y la perilla no compite con el computador. El botón Leer ajustes pide `$CF`. Leer rampas pide el perfil.

En la captura de esta sesión el equipo contestó límites de 50 °C y 210 °C, bandas de 4 °C y 6 °C, aire al enfriar activado, y ganancias Kp 24,6 y Ki 0,10. Son los valores de esa placa en ese momento, leídos del equipo, no una tabla universal.

## 2. Límites y bandas

La temperatura mínima es el final del enfriamiento: el aire y el ciclo se dan por terminados al bajar hasta ahí. La máxima es el corte de seguridad: si se alcanza, las salidas se apagan. La consigna de un escalón no puede pasar de 250 °C ni de esa máxima, así que la máxima tiene que quedar por encima del escalón más alto del perfil.

La banda de entrada dice cuándo la temperatura ya está «en meseta» y puede empezar a contar el tiempo. La banda de salida dice hasta dónde puede alejarse sin abortar esa cuenta. Ajustarlas demasiado estrechas hace que una placa con inercia no llegue a contar. Dejarlas anchas da por buena una meseta que todavía se está moviendo.

El retraso de arranque (`00:00` a `12:00`) y el aire al enfriar también se guardan aquí. `00:00` arranca el perfil al momento. El aire sopla en el aviso final y durante el enfriamiento, hasta la mínima.

## 3. Autoajuste del PI

El lazo no usa derivada. Kp y Ki salen de un ensayo: el equipo oscila alrededor de una consigna, mide la respuesta y calcula las ganancias al estilo Ziegler–Nichols para un PI. Studio lanza ese programa, sigue los ciclos en la curva y muestra el resultado.

Las ganancias nuevas se escriben en la EEPROM solo si el ensayo termina. Cortarlo a medias deja las anteriores. Por eso el botón de sobrescribir a mano existe, y por eso no es el camino normal: el camino normal es dejar que el autoajuste acabe.

## 4. Comprobar con un HEAT

Después del ajuste se corre un perfil corto, de escalones que suben, y se mira la curva a 1 Hz. Lo que hay que ver es si la temperatura persigue la consigna sin un sobrepaso largo, si cada meseta llega a contar, y si al final el calor se apaga y el aire enfría. El registro de eventos marca cada cambio de fase. Exportar el CSV deja la corrida fuera de la pantalla, para compararla con la siguiente.

Si durante la subida la potencia se queda al tope y la temperatura no avanza, el firmware corta y avisa. Si el sensor no mide, el calor no tiene por qué estar encendido: el arranque y el fallo dejan las salidas apagadas.

## Material de esta pieza

- Vídeo: `videos/05-calibracion.mp4` y `videos/05-calibracion.srt`
- Capturas de la sesión: `referencias/05-calibracion/`

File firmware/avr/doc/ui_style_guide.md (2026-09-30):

# Guía de estilo — HotPanel (ST7920 128×64)

Cómo está dibujada y cómo se comporta **HotPanel**, la interfaz a bordo de HotPlate. Describe el binario actual (`home_view.c`). Complementa [product_features.md](product_features.md) (qué hace el producto) y [architecture.md](architecture.md) (cómo está organizado el código). Bitmaps, diffs y animaciones: [st7920_pantalla.md](st7920_pantalla.md).

Actualizado: 2026-09-29.

Hay **una sola vista**, `VIEW_HOME`. El router (`ui_router.c`) siempre entra ahí. Lo que el usuario percibe como pantallas distintas son modos de esa misma vista: Heat en reposo, Heat con un ciclo en marcha, aviso USB, lista de ajustes y el cierre de un ciclo terminado o fallido.

**Capturas.** Las imágenes de esta guía salen del `home_view.c` real compilado en el host: solo se simulan el LCD y los servicios (`tools/ui_screens/`). Tras tocar HotPanel se regeneran con:

```bash
cd firmware/avr && make ui-screens   # → doc/img/hotpanel/*.png
```

Los datos de ejemplo son siempre los mismos: perfil R1 150 °C / 90 s, R2 180 °C / 60 s, R3 220 °C / 30 s, R4 apagada, y retraso `01:30`.

---

## 1. Límites de la pantalla

| Recurso | Qué implica al diseñar |
|---|---|
| 128 × 64 px | Todo cabe en un rectángulo pequeño. No hay segundas páginas; el único desplazamiento es el de la lista de Setup (§ 5) |
| 1 bit (encendido / apagado) | Sin grises, degradados ni anti-alias. El único énfasis es **invertir** la banda: fondo encendido y glifo apagado |
| Encoder + pulsación | Girar a la derecha (`EVT_ENCODER_NEXT`) avanza el cursor **hacia abajo**. Girar a la izquierda sube. Pulsar confirma |
| Fuentes enlazadas | `FONT_5X7` (celda de 6 px: 5 de glifo + 1 de separación; en el panel caben unas **15 columnas**), `FONT_8X12` (temperatura nativa, trazo de 2 px, avance 9 px; solo `-.0123456789°CER`), `FONT_5X7_X2` (la tabla 5×7 a 2×, solo para `USB`) y `FONT_ICONS` (16×16) |

`font8x12.c` se genera con `tools/gen_fonts.py` (el dibujo de cada glifo está ahí). `ui_display.c` y `ui_window.c` tampoco forman parte del binario. El icono USB de `font_icons.c` solo se compila con `-DFONT_ICONS_USB`: el overlay USB usa el texto `USB` a 2×.

### Glifos 5×7

Cada glifo son 5 bytes, uno por columna; el bit 0 es la fila superior y el bit 6 la inferior. Una letra simétrica tiene que tener **una fila central (fila 3)** donde se crucen los trazos: con 7 filas hay 3 arriba, 1 en el centro y 3 abajo. Por ejemplo, la `X` es `0x63, 0x14, 0x08, 0x14, 0x63`:

```
X...X   fila 0
X...X   fila 1
.X.X.   fila 2
..X..   fila 3  ← cruce
.X.X.   fila 4
X...X   fila 5
X...X   fila 6
```

La diagonal de 5 columnas no cabe en 7 filas a un píxel por fila, así que los extremos se duplican (filas 0–1 y 5–6). Un patrón de diagonal pura (`0x41, 0x22, 0x14, 0x22, 0x41`) deja la fila 3 vacía y la letra se ve partida, sobre todo a 2×.

El límite de flash es **16 384 bytes**. Cualquier cambio visual se mide con `make size`.

---

## 2. Distribución de la pantalla

```
x=0        x=32                            x=127
┌──────────┬──────────────────────────────────┐ y=0
│          │                                  │
│ ┌──────┐ │                                  │
│ │ Heat │ │                                  │
│ │16×16 │ │             panel                │
│ └──────┘ │                                  │
│          │                                  │
├──────────┤                                  │ y=32
│          │                                  │
│ ┌──────┐ │                                  │
│ │ Set. │ │                                  │
│ │16×16 │ ├──────────────────────────────────┤ y=54
│ └──────┘ │  pie (RUN / STOP / EXIT)         │
│          │                                  │
└──────────┴──────────────────────────────────┘ y=63
```

| Zona | Posición | Contenido |
|---|---|---|
| Barra lateral | x = 0…31, y = 0…63 (toda la altura) | Dos casillas **iguales** de 32 × 32 px: Heat (y = 0…31) y Settings (y = 32…63), cada una con su icono `FONT_ICONS` de **16 × 16 px centrado** (x = 8…23; y = 8…23 y 40…55). La casilla con foco se dibuja invertida. Una línea vertical en x = 31 separa la barra del panel |
| Panel | x = 32…127, y = 0…53; texto desde x = 36 | Temperatura y fase, o la lista de ajustes |
| Pie | x = 32…127, y = 54…63 (10 px), solo bajo el panel | Acción de la pulsación: `RUN`, `STOP` o `EXIT` |

El panel solo se borra entero al **cambiar de modo** (Heat, ajustes o USB). Dentro de un modo se repinta la banda que cambió (`HOME_DIRTY_SIDE`, `TEMP`, `BODY`, `FOOT`), para que la temperatura no parpadee. Un borrado total (`st7920_clear_gdram`) ocurre solo al entrar en la vista.

---

## 3. Modo Heat

Es el modo de reposo y el de un ciclo en marcha. La casilla Heat tiene el foco.

Cuatro líneas centradas. Temperatura, fase y perfil siguen en su sitio; el transcurrido va debajo.

| Reposo | Reposo sin rampas |
|---|---|
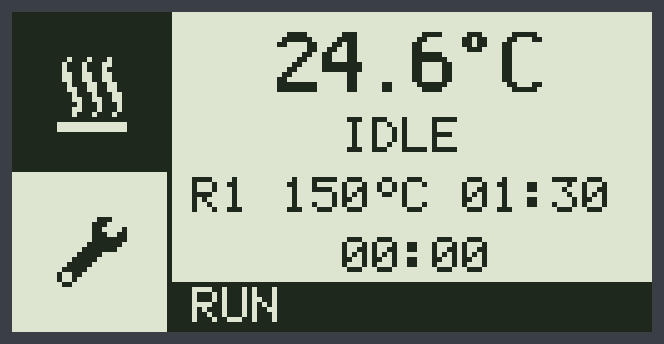
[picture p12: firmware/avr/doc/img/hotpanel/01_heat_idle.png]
Heat en reposo: 24.6 °C, IDLE, R1 150 °C 01:30, 00:00, pie RUN
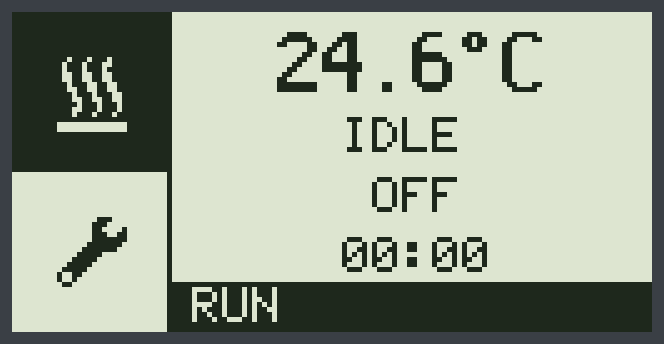
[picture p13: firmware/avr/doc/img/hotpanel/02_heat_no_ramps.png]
Heat sin rampas: la línea de perfil muestra OFF
|  |  |

| Línea | y | Qué muestra |
|---|---|---|
| Temperatura | 3 (banda de 14 px, glifo de 12) | `123.4°C` con `FONT_8X12` nativa (7 × 9 px = 63 px). Si el sensor no es válido, `ERR` en la misma fuente |
| Fase | 21 | Nombre corto de la fase (tabla de abajo) |
| Perfil | 33 | `R2 180°C 01:30`: rampa, consigna con `°C` y tiempo. En meseta es `mm:ss`; el retraso es `hh:mm` |
| Transcurrido | 45 | `mm:ss` desde el arranque (`t_elapsed_s`). En reposo, `00:00`. Pasados 99 min el minuto gana un dígito (`100:00`). Termina en y = 52; el pie sigue en y = 54 |

La línea de perfil depende del momento:

- **En reposo**, con al menos una rampa: `R1`, la temperatura de la rampa 1 y el retraso configurado (`hh:mm`, tope 12:00).
- **Sin rampas:** `OFF`. Pulsar `RUN` en ese estado no arranca y suena la alarma.
- **Durante la subida y la meseta:** el número de rampa en curso, la consigna activa (`t_set_c`) y el tiempo que queda (`t_remain_s`).
- **En espera:** `R1`, la temperatura de la rampa 1 y el tiempo que queda en `hh:mm`.
- **En enfriamiento y aviso de fin:** sigue mostrando `R1` y su temperatura; el tiempo es `t_remain_s` en `mm:ss`.

| Espera (`WAIT`) | Subida de R2 (`RUN`) | Meseta de R2 (`RUN`) |
|---|---|---|
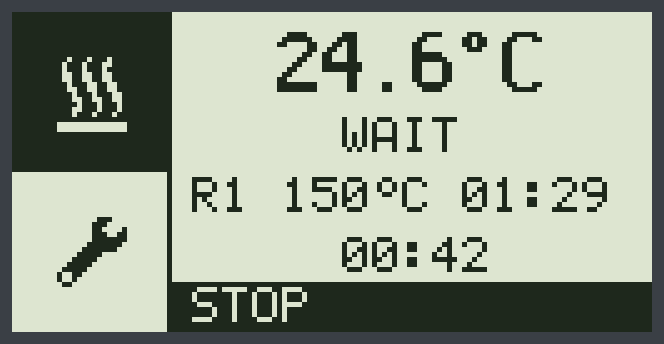
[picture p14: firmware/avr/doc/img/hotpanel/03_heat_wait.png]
Cuenta atrás del retraso: WAIT, R1 150 °C 01:29, pie STOP
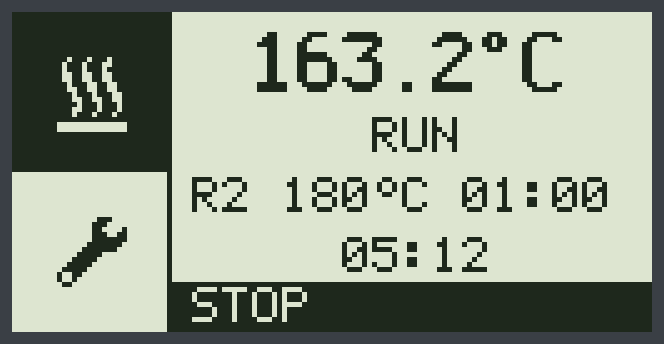
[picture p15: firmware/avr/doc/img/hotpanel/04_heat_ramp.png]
Subida hacia la rampa 2: 163.2 °C, RUN, R2 180 °C 01:00
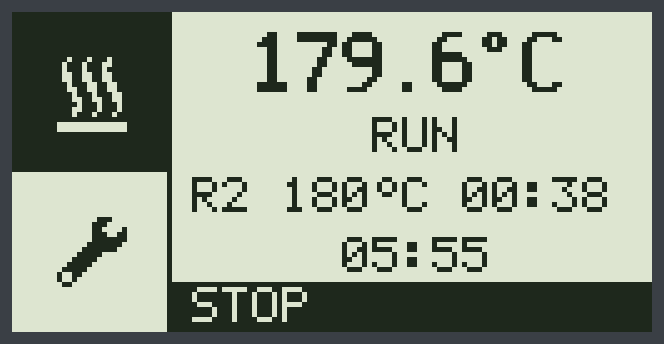
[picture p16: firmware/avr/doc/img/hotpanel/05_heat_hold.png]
Meseta de la rampa 2: 179.6 °C, RUN, R2 180 °C 00:38
|  |  |  |

| Enfriamiento (`AIR`) | Aviso de fin (`ALM`) |
|---|---|
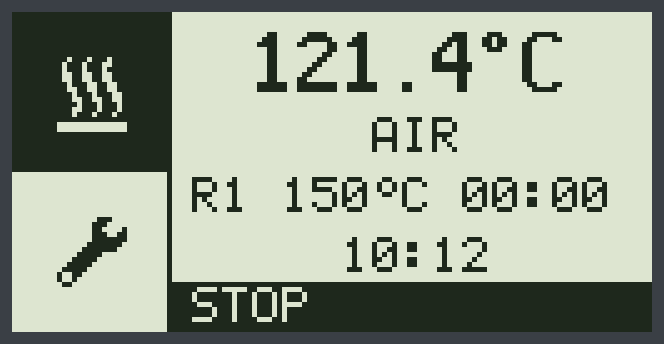
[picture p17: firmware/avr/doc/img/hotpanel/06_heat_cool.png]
Enfriamiento con aire: AIR, el perfil vuelve a R1
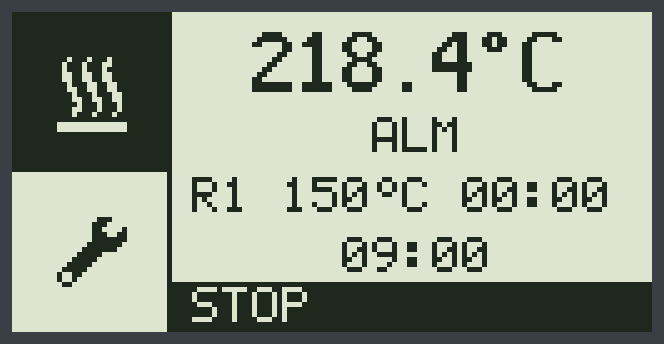
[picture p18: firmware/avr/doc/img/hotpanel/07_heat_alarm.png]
Aviso de fin de ciclo: ALM, pie STOP
|  |  |

| Terminado (`END`) | Fallo (`ERR`) |
|---|---|
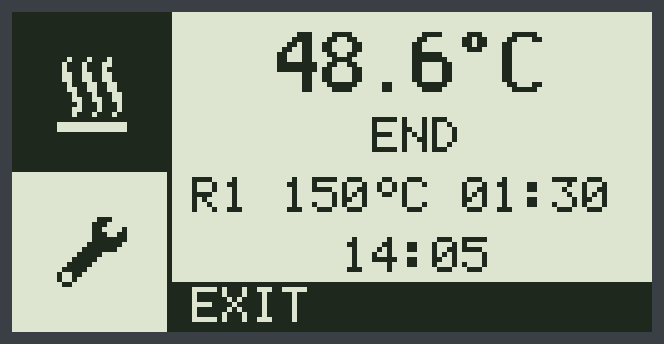
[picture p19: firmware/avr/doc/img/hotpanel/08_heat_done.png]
Ciclo terminado: END, pie EXIT
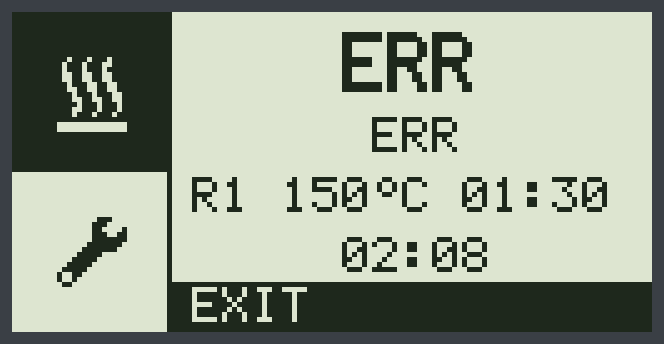
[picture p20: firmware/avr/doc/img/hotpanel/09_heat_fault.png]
Fallo de sensor: ERR en la temperatura y en la fase, pie EXIT
|  |  |

### Nombres de fase en pantalla

El nombre sale de `program_phase_name()`. La meseta (`PH_HOLD`) comparte la etiqueta de la subida.

| Fase interna | En pantalla |
|---|---|
| Reposo | `IDLE` |
| Cuenta atrás | `WAIT` |
| Subida y meseta | `RUN` |
| Enfriamiento | `AIR` |
| Aviso de fin | `ALM` |
| Terminado | `END` |
| Fallo | `ERR` |

`PRE` y `STAB` siguen en la tabla de textos porque los códigos de fase 2 y 3 están reservados (no se renumera `$HP`), pero HEAT ya no entra en esas fases: la rampa 1 es el primer escalón.

### Qué hace el mando

| Estado | Girar | Pulsar | Pie |
|---|---|---|-----|
| Reposo, foco en Heat | Pasa a la casilla Settings | Arranca HEAT con el reloj `hh:mm` ya guardado. Si no hay rampas o el arranque falla, pitido de alarma | `RUN` |
| Ciclo en marcha (espera, rampas o enfriamiento) | No hace nada | Cancela el ciclo (`device_session_safe_stop`). El ventilador no arranca | `STOP` |
| Aviso de fin (`ALM`) | No hace nada | Cierra el aviso (`program_user_ack`) y pasa a `AIR` o a `END` | `STOP` |
| Terminado (`END`) o fallo (`ERR`) | No hace nada | Vuelve a reposo (`IDLE`) | `EXIT` |

Mientras hay un ciclo o la sesión USB está activa, el foco queda forzado en Heat: no se puede abrir ajustes.

Cada lectura de sensor (1 Hz) repinta la temperatura. Si hay un ciclo en marcha, también repinta la fase, el perfil y el transcurrido. El pie no se toca en ese refresco.

---

## 4. Modo USB

Cuando el PC toma el control (`DEVICE_USB`, normalmente `AT+MODE=1`), el panel de Heat se sustituye por:

1. La temperatura, igual que en Heat.
2. La etiqueta **`USB`** a 2× (`FONT_5X7_X2`) en la línea de fase. No se muestran la fase, el perfil ni el transcurrido.

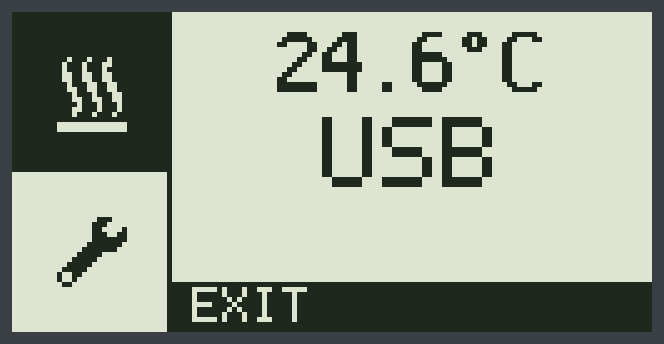
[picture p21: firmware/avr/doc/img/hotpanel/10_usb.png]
Overlay USB: temperatura y USB a 2×, pie EXIT


| Acción | Efecto |
|---|---|
| Girar | Ignorado |
| Pulsar | Sale del modo USB y vuelve al control manual (`device_session_leave_manual`), con foco en Heat |
| Pie | `EXIT`, invertido |

Ajustes no se puede abrir mientras dure la sesión.

---

## 5. Modo Settings

### Vista previa y edición

Girar hasta la casilla Settings **ya muestra** la lista y recarga de EEPROM las rampas y el retraso de HEAT. En esa vista previa ninguna fila está invertida y el pie está vacío: todavía no se edita. Girar sigue cambiando de casilla.

Pulsar entra en la lista (`HOME_PAGE_SETTINGS`):

- El cursor arranca en R1.
- Girar mueve el cursor por **seis** posiciones: R1, R2, R3, R4, retraso y, al final, el pie `EXIT`.
- La fila bajo el cursor se invierte. Cuando el cursor está en el pie, se invierte `EXIT`.
- Mover el cursor y entrar o salir de un campo no pitan.
- Pulsar sobre `EXIT` cierra la lista, vuelve el foco a Heat y sale del modo de edición.

| Vista previa | Cursor en R1 | Cursor en R4 (apagada) |
|---|---|---|
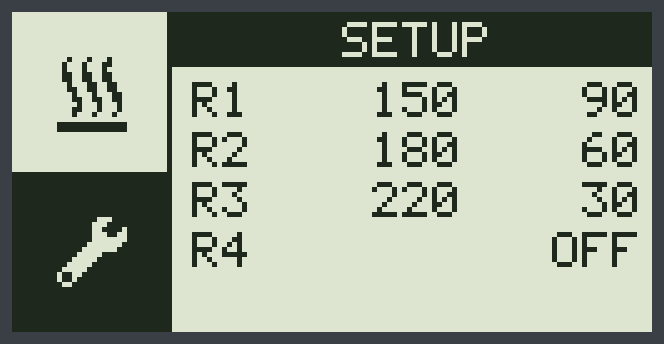
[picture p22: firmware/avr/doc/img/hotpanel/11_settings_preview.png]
Vista previa de Setup: sin fila invertida y sin pie
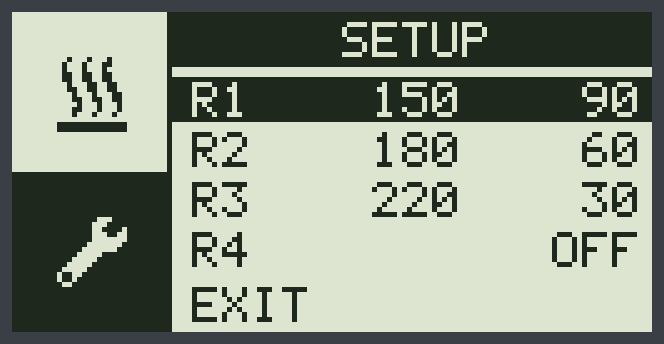
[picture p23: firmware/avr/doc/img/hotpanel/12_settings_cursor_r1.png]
Lista abierta con el cursor en R1
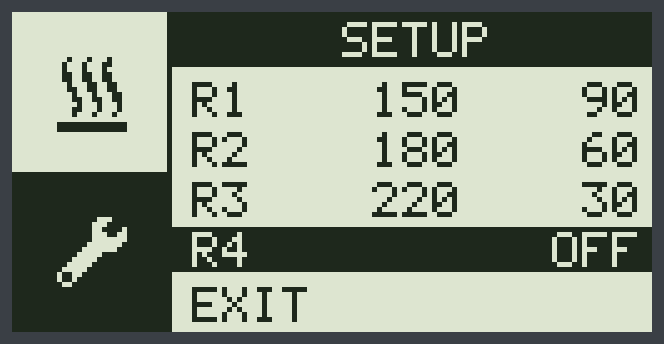
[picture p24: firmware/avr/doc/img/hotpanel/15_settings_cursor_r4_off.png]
Cursor en R4 apagada
|  |  |  |

| Cursor en DLY (la lista sube) | Cursor en `EXIT` |
|---|---|
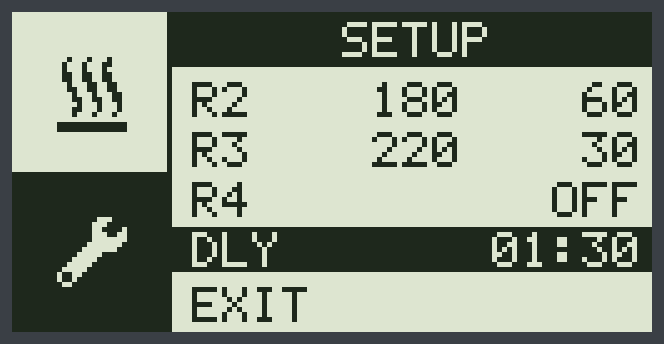
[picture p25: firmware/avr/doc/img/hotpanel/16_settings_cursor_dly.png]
Cursor en DLY: se ven R2 a DLY
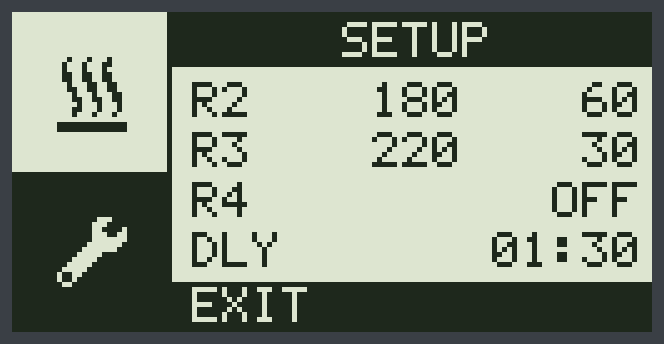
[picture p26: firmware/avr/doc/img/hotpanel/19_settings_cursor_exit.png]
Cursor en el pie EXIT, invertido
|  |  |

### Contenido de cada fila

Cabecera **`SETUP`**, invertida, de 11 px de alto. Dos píxeles en blanco (y = 11…12) y después **cuatro filas visibles** desde y = 13, con paso de 10 px. Cada fila es una banda de 9 px (1 px + glifo de 7 + 1 px) que entra entera en el inverso, seguida de 1 px que no se invierte y la separa de la de abajo. Las bandas ocupan y = 13…21, 23…31, 33…41 y 43…51; el pie sigue en y = 54. El nombre va a la izquierda y el valor a la derecha.

Hay cinco opciones y solo caben cuatro. Con el cursor en R1…R4 se ven R1…R4. Con el cursor en DLY o en `EXIT` la lista sube una fila y se ven R2…DLY. La vista previa (sin editar) muestra siempre R1…R4.

| Fila | En pantalla | Valor |
|---|---|---|
| R1…R4 activas | `R1 150 90` | Temperatura en °C y meseta en **segundos** (no `mm:ss`) |
| Rampa apagada | `R2 OFF` | — |
| Retraso | `DLY 01:30` | Reloj `hh:mm` (`01:30` = 1 h 30 min). Tope `12:00` |

Un asterisco (`*`) marca el campo que se está editando: delante de la temperatura, delante de la meseta, delante de las horas del retraso (`*01:30`) o en los dos puntos al editar minutos (`01*30`).

| Editando temperatura | Editando meseta | Retraso: horas | Retraso: minutos |
|---|---|---|---|
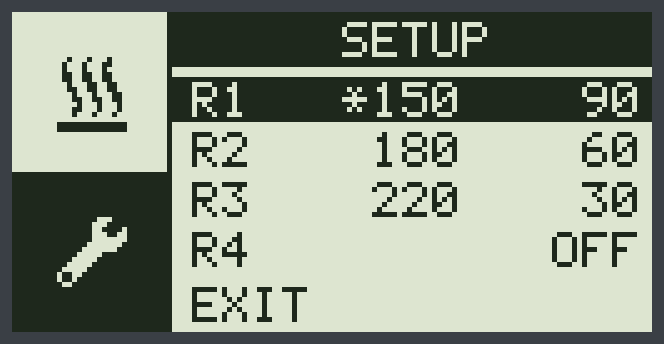
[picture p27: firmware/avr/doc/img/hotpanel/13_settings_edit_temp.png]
R1 con asterisco delante de la temperatura
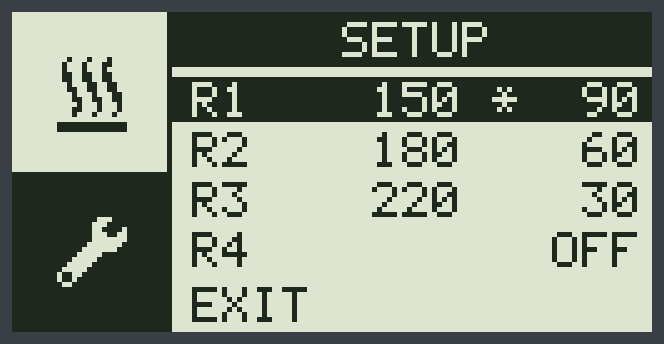
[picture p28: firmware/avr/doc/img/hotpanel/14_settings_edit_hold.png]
R1 con asterisco delante de la meseta
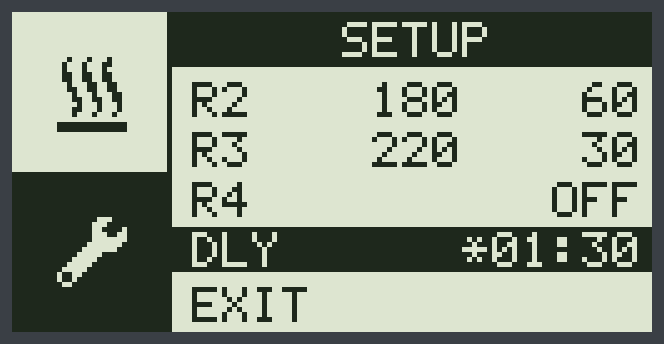
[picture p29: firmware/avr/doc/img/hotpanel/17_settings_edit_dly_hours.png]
DLY *01:30 editando horas
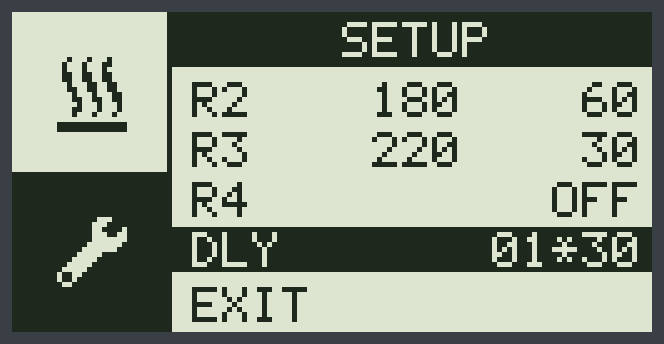
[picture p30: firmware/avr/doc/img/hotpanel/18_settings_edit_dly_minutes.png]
DLY 01*30 editando minutos
|  |  |  |  |

### Editar una rampa

Pulsar recorre tres estados: **nada → temperatura → meseta → nada**. Girar solo cambia el valor cuando hay un campo marcado, y cada paso se guarda en EEPROM al momento, con un pulso corto de confirmación.

| Campo | Paso | Límites |
|---|---|---|
| Temperatura | 5 °C | Entre `temp_min_c` y `temp_max_c` |
| Meseta (`hold_s`) | 30 s | De 30 s a 60 min |
| Retraso, horas | 1 h | De 0 a 12. En 12 h los minutos pasan a 00. Pulsar entra aquí primero (`*HH:MM`) |
| Retraso, minutos | 1 min | De 0 a 59. Segunda pulsación (`HH*MM`). En 12 h no se mueven |

Reglas al apagar o encender rampas:

- **R1 no se apaga.** Si se intenta bajar de `temp_min_c`, se queda en ese mínimo.
- **R2…R4** se apagan en dos pasos: bajar de `temp_min_c` deja la temperatura en 0 (pendiente de apagar, la fila sigue mostrando el número 0) y la pulsación siguiente confirma, recortando el perfil en esa rampa (`ramp_n`).
- Una rampa en `OFF` se enciende girando a la derecha o pulsando. Nace con temperatura `temp_min_c` y meseta de 30 s, y el cursor queda editando la temperatura.
- Encender R3 enciende también las anteriores que faltaran, porque el perfil es siempre R1…Rn sin huecos.

### Qué no se repinta

Con la lista visible, una lectura nueva del sensor **no** marca la pantalla. Así el cursor y los valores no parpadean cada segundo.

---

## 6. Textos

Todos los textos salen de `lib/i18n/i18n.c` mediante `i18n_tr_hash(I18N_*)`. Son inglés, mayúsculas y como mucho 8 caracteres (`SETTINGS` no cabe: la cabecera es `SETUP`).

| Id | Texto | Dónde |
|----|---|---|
| `I18N_PHASE_IDLE` … | `IDLE` `WAIT` `PRE` `STAB` `RUN` `AIR` `ALM` `END` `ERR` | Línea de fase |
| `I18N_BTN_START` | `RUN` | Pie para arrancar |
| `I18N_BTN_CANCEL` | `STOP` | Pie para cancelar |
| `I18N_USB_EXIT` | `EXIT` | Pie de USB, de ajustes y de fin/fallo |
| `I18N_TITLE_USB` | `USB` | Línea central del modo USB |
| `I18N_TITLE_SETTINGS` | `SETUP` | Cabecera de ajustes |
| `I18N_SET_DELAY` | `DLY` | Fila de retraso |
| `I18N_OFF` | `OFF` | Rampa apagada, o perfil vacío en Heat |

No hay glifo de “intro” en el pie: la acción es solo la palabra.

---

## 7. Checklist al tocar HotPanel

- Repintar solo la banda sucia. El panel completo se borra al cambiar de modo, no en cada lectura.
- Heat conserva temp 2×, fase y perfil (`Rx T°C`). El transcurrido va en y = 45 (`00:00` en reposo). El overlay USB no lo pinta.
- Setup: 2 px bajo `SETUP`. Cada opción es una banda de 9 px (1 px sobre y bajo la letra, invertidos) más 1 px de separación fuera del inverso. Cuatro filas visibles con desplazamiento; la lista termina antes del pie (y = 54).
- Texto nuevo pasa por `I18N_*`. Cabe en 8 caracteres y en las ~15 columnas del panel.
- Girar a la derecha baja el cursor.
- Un ciclo en marcha o una sesión USB dejan el foco en Heat y no abren ajustes.
- Medir el flash (`make size`) antes de volver a enlazar iconos o una fuente más grande.
- Regenerar las capturas (`make ui-screens`) y revisar que la guía siga coincidiendo con ellas.

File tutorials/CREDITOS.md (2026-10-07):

# Créditos de audio

Los vídeos no llevan voz. La música y el golpe de entrada de cada tutorial salen de la biblioteca CC0 1.0 incluida en el kit de edición. No hace falta atribución; queda anotada igual.

| Archivo | Uso | Licencia |
|---|---|---|
| `audio/music-inspiring-orchestral.mp3` | Promo | CC0 1.0 |
| `audio/music-ambient-piano.mp3` | Tutoriales 01 a 05 | CC0 1.0 |
| `audio/whoosh-soft.wav` | Entrada del título de cada tutorial | CC0 1.0, generado con ffmpeg para esa biblioteca |

Las imágenes de `referencias/` son fotos del proceso, capturas de HotPlate Studio y exportaciones de la interfaz HotPanel del firmware. La imagen `hero-producto.jpg` es una composición del equipo terminado a partir de esas fotos, de la LCD y de Studio; es la que usa el hero de la landing.

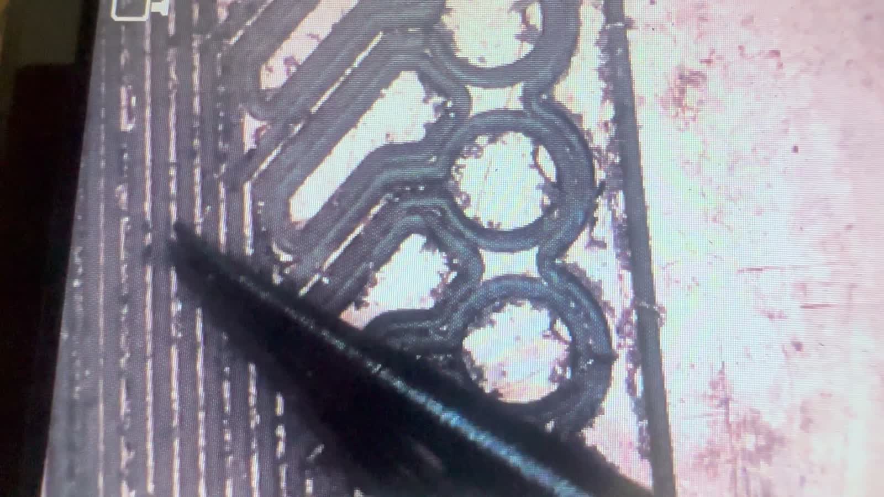
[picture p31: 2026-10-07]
tutorials/referencias/01-pcb/revision-microscopio.jpg

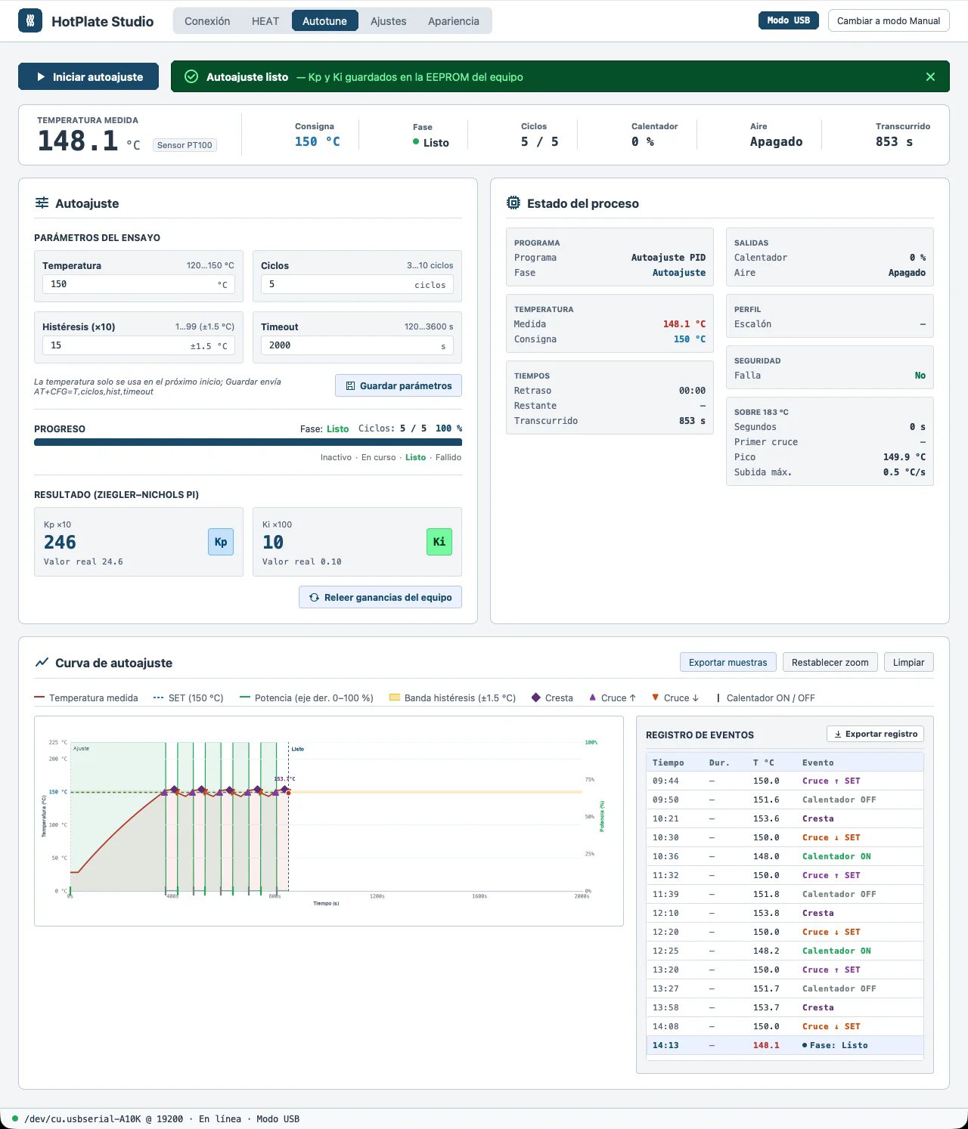
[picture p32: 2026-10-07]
tutorials/referencias/04-studio/studio-autotune.jpg

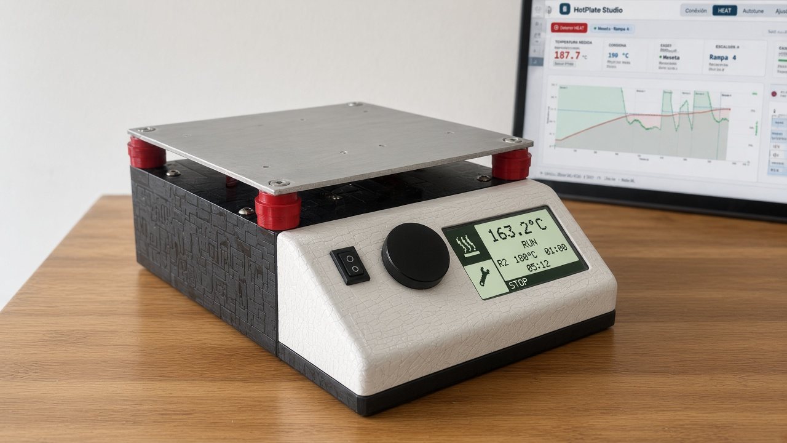
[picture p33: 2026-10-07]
tutorials/referencias/hero-producto.jpg

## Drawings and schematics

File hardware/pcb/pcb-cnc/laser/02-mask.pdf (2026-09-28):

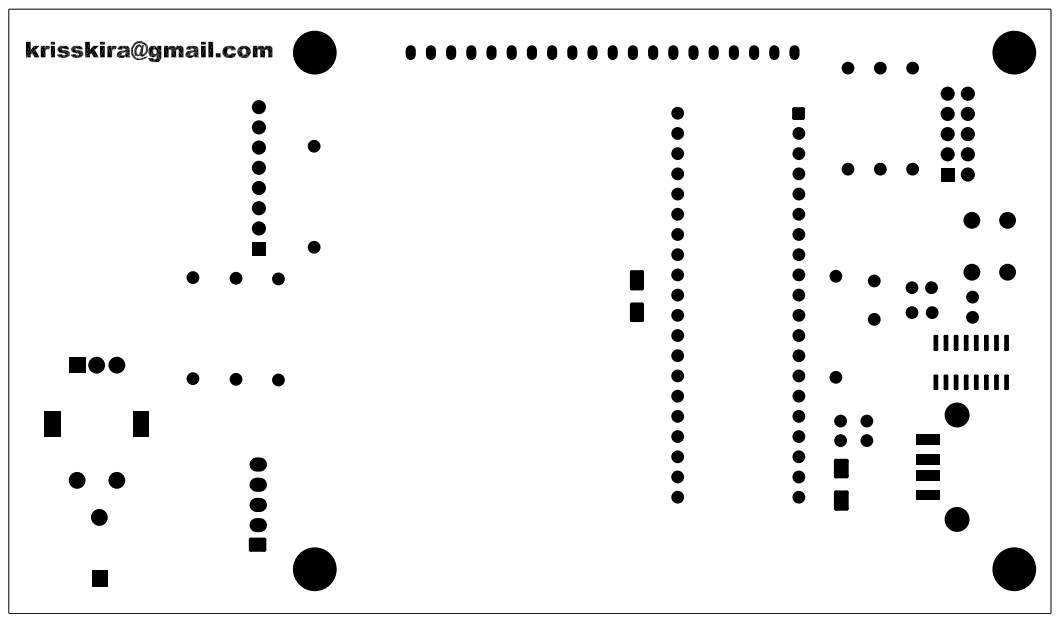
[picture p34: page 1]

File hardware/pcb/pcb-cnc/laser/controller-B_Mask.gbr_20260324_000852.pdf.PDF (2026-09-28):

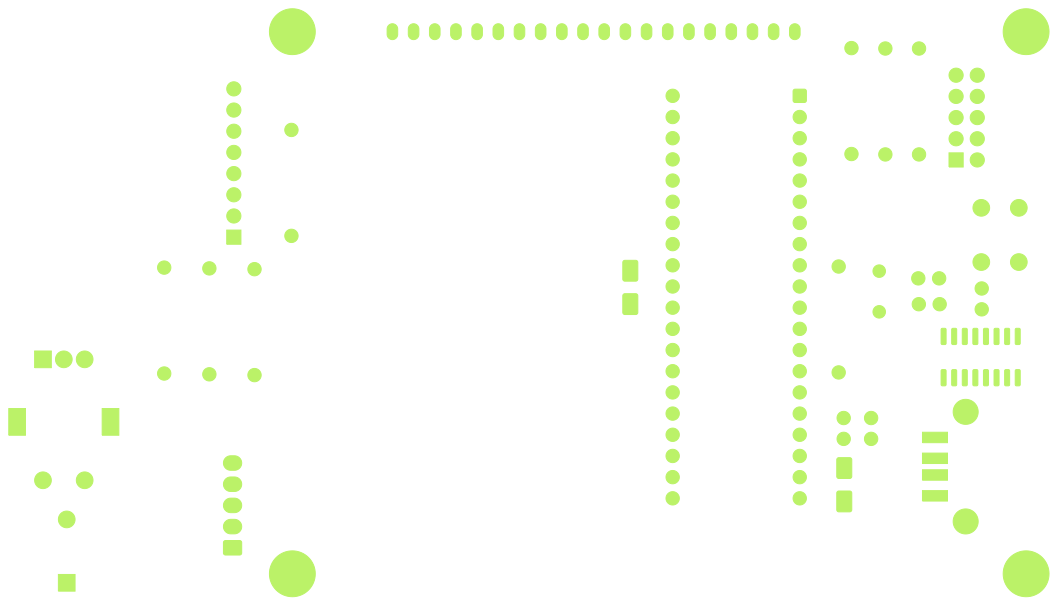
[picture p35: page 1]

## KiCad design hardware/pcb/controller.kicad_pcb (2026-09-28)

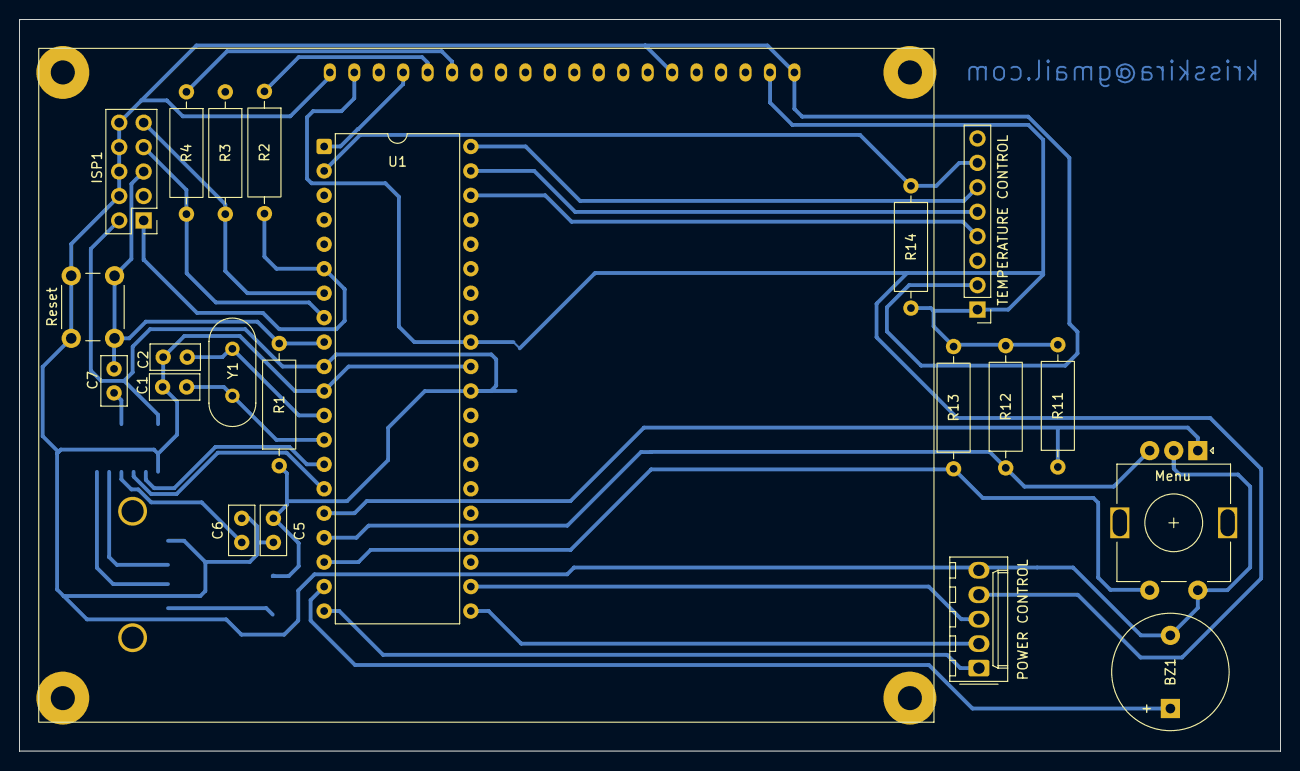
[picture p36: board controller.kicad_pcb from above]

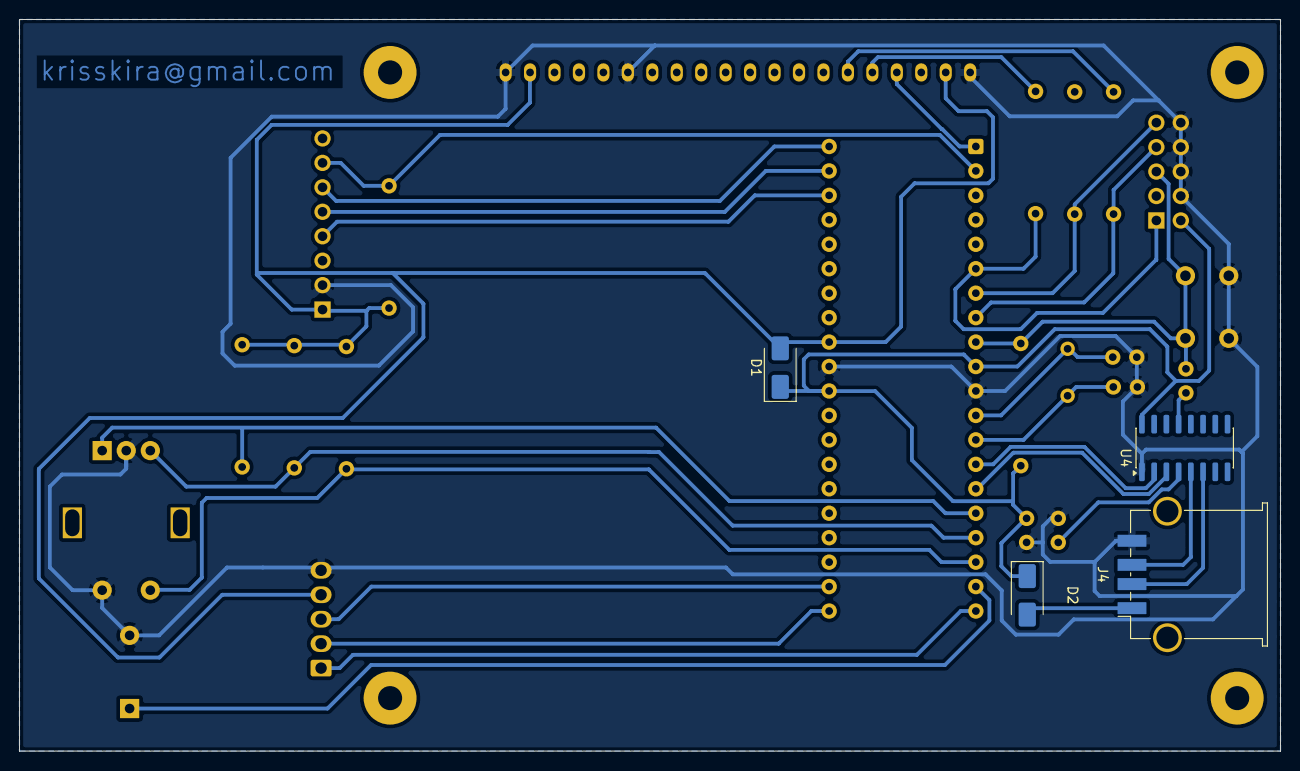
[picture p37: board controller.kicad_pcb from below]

Board: 2 copper layers, 131.0 x 76.0 mm, 26 parts (4 on the bottom side), 30 nets.

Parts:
BZ1: Buzzer; Buzzer_12x9.5RM7.6
C1, C2: 27pf; C_Disc_D5.0mm_W2.5mm_P2.50mm
C5, C6: 0.1uF; C_Disc_D5.0mm_W2.5mm_P2.50mm
C7: 100nF; C_Disc_D5.0mm_W2.5mm_P2.50mm
D1, D2: SS14; D_SMA
ISP1: Conn_02x05_Odd_Even; PinHeader_2x05_P2.54mm_Vertical
J4: USB_A; USB_A_TE_292303-7_Horizontal
LCD1: ST7920-12864B; st7920-12864b-v2
Menu: RotaryEncoder_Switch; RotaryEncoder_Alps_EC11E-Switch_Vertical_H20mm
POWER CONTROL: Conn_01x05_Pin; Molex_KK-254_AE-6410-05A_1x05_P2.54mm_Vertical
R1, R3, R4, R11, R12, R13, R14: 10K; R_Axial_DIN0309_L9.0mm_D3.2mm_P12.70mm_Horizontal
R2: 330; R_Axial_DIN0309_L9.0mm_D3.2mm_P12.70mm_Horizontal
Reset: SW_Push_Dual_x2; SW_PUSH_6mm_H5mm
TEMPERATURE CONTROL: Max31865; PinHeader_1x08_P2.54mm_Vertical
U1: ATmega16L-8P; DIP-40_W15.24mm
U4: CH340C; SOIC-16_3.9x9.9mm_P1.27mm
Y1: 16Mhz; Crystal_HC49-4H_Vertical

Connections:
+5V: D1.2 (A), LCD1.2 (VCC), LCD1.19 (BLA), POWER CONTROL.4, R11.2, R12.2, R13.2, R14.2, TEMPERATURE CONTROL.1, U1.32 (AREF)
BUZZER: BZ1.1 (+), U1.19 (PD5)
CS_MAX31865: R14.1, TEMPERATURE CONTROL.7, U1.2 (PB1)
FAN: POWER CONTROL.3, U1.22 (PC0)
GNDREF: BZ1.2 (-), C1.2, C2.2, C5.1, C6.2, ISP1.4, ISP1.6, ISP1.8, ISP1.10, J4.4 (GND), LCD1.1 (GND), LCD1.15 (PSB), LCD1.20 (BLK), Menu.C, Menu.S2, POWER CONTROL.5, Reset.1 (C), TEMPERATURE CONTROL.2, U1.11 (GND), U1.31 (GND), U4.1 (GND)
ICSP_CLK: ISP1.7, R4.2, U1.8 (PB7)
ICSP_MISO: ISP1.9, R3.2, U1.7 (PB6)
ICSP_MOSI: ISP1.1, R2.2, U1.6 (PB5)
ICSP_RST: C7.1, ISP1.5, R1.2, Reset.2 (D), U1.9 (~RESET)
LCD_RS: LCD1.4 (RS(CS*)), U1.1 (PB0)
MENU_CLK: Menu.A, R11.1, U1.16 (PD2)
MENU_DT: Menu.B, R12.1, U1.17 (PD3)
MENU_SW: Menu.S1, R13.1, U1.18 (PD4)
MOSI: LCD1.5 (R/W(SID*)), R2.1
unnamed: D2.2 (A), J4.1 (VBUS)
unnamed: J4.3 (D+), U4.5 (UD+)
unnamed: J4.2 (D-), U4.6 (UD-)
unnamed: C6.1, U4.4 (V3)
unnamed: C7.2, U4.13 (~DTR)
PTC1: POWER CONTROL.2, U1.21 (PD7)
PTC2: POWER CONTROL.1, U1.20 (PD6)
RX: U1.14 (PD0), U4.2 (TXD)
SCK: LCD1.6 (E(SCLK)), R4.1
SOFT_MISO: TEMPERATURE CONTROL.5, U1.39 (PA1)
SOFT_MOSI: TEMPERATURE CONTROL.6, U1.40 (PA0)
SOFT_SCK: TEMPERATURE CONTROL.4, U1.38 (PA2)
TX: U1.15 (PD1), U4.3 (RXD)
V_TARGET: C5.2, D1.1 (K), D2.1 (K), ISP1.2, R1.1, U1.10 (VCC), U1.30 (AVCC), U4.16 (VCC)
xtal1: C1.1, U1.13 (XTAL1), Y1.1
xtal2: C2.1, U1.12 (XTAL2), Y1.2

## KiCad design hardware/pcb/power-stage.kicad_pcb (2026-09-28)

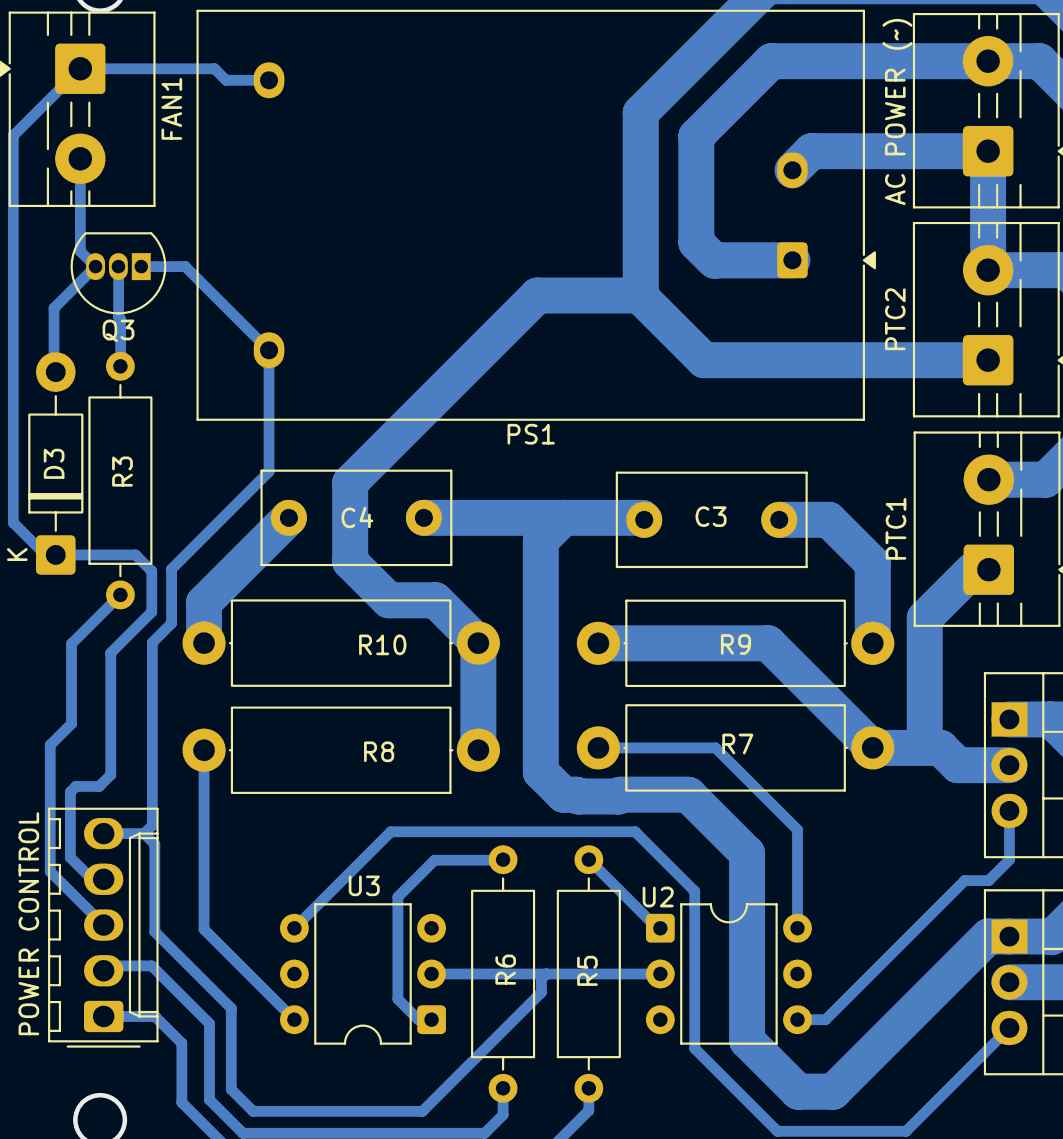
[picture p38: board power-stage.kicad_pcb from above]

Board: 2 copper layers, 21 parts (0 on the bottom side), 19 nets.

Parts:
AC POWER (~): Screw_Terminal_01x02; TerminalBlock_MaiXu_MX126-5.0-02P_1x02_P5.00mm
C3, C4: 100nf; C_Rect_L10.3mm_W5.0mm_P7.50mm_MKS4
D3: 1N4004; D_DO-41_SOD81_P10.16mm_Horizontal
FAN1: Screw_Terminal_01x02; TerminalBlock_MaiXu_MX126-5.0-02P_1x02_P5.00mm
POWER CONTROL: Conn_01x05_Pin; Molex_KK-254_AE-6410-05A_1x05_P2.54mm_Vertical
PS1: HLK-PM01; Converter_ACDC_Hi-Link_HLK-PMxx
PTC1, PTC2: Screw_Terminal_01x02; TerminalBlock_MaiXu_MX126-5.0-02P_1x02_P5.00mm
Q1, Q2: BT136-600; TO-220-3_Vertical
Q3: 2N2222; TO-92_Inline
R3: 330; R_Axial_DIN0309_L9.0mm_D3.2mm_P12.70mm_Horizontal
R5, R6: 220; R_Axial_DIN0309_L9.0mm_D3.2mm_P12.70mm_Horizontal
R7, R8, R9, R10: 100; R_Axial_DIN0414_L11.9mm_D4.5mm_P15.24mm_Horizontal
U2, U3: MOC3021M; DIP-6_W7.62mm

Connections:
LINE: AC POWER (~).1, PS1.2 (AC/N), PTC1.2, PTC2.2
NEUTRO: AC POWER (~).2, C3.2, C4.2, PS1.1 (AC/L), Q1.1 (A1), Q2.1 (A1)
unnamed: C3.1, R9.2
unnamed: C4.1, R10.2
unnamed: D3.2 (A), FAN1.2, Q3.3 (C)
unnamed: PTC1.1, Q1.2 (A2), R7.1, R9.1
unnamed: PTC2.1, Q2.2 (A2), R8.1, R10.1
unnamed: Q1.3 (G), U2.4
unnamed: Q2.3 (G), U3.4
unnamed: Q3.2 (B), R3.2
unnamed: R5.2, U2.1
unnamed: R6.2, U3.1
unnamed: R7.2, U2.6
unnamed: R8.2, U3.6
P_FAN: POWER CONTROL.3, R3.1
P_GND: POWER CONTROL.5, PS1.3 (-Vout), Q3.1 (E), U2.2, U3.2
P_PTC1: POWER CONTROL.1, R5.1
P_PTC2: POWER CONTROL.2, R6.1
P_VCC: D3.1 (K), FAN1.1, POWER CONTROL.4, PS1.4 (+Vout)

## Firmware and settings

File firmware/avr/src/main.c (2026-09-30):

/*
 * Firmware único: HOME dos columnas, Ajustes, sesión AT, sensor y PID.
 * Entrada USB: solo AT+MODE=1. Ver doc/usb-automation.md.
 */

#include <avr/io.h>
#include <stdint.h>
#include <avr/pgmspace.h>

#include "app/app_config.h"
#include "app/app_state.h"
#include "services/outputs.h"
#include "services/buzzer_seq.h"
#include "services/process.h"
#include "services/cfg_store.h"
#include "services/pid.h"
#include "services/pid_atune.h"
#include "services/sensor_service.h"
#include "services/safety.h"
#include "services/at_cmd.h"
#include "services/telemetry.h"
#include "services/device_session.h"
#include "ui/ui_router.h"

#include "lib/avr_spi/avr_spi.h"
#include "lib/avr_delay/avr_delay.h"
#include "lib/avr_uart/avr_uart.h"
#include "lib/st7920/st7920.h"
#include "lib/encoder/encoder.h"
#include "lib/ports/ports.h"

static app_state_t g_state;
static process_phase_t s_prev_phase;
static atune_phase_t s_prev_atune;

int main(void)
{
    avr_spi_master_init(SPI_DIV_8);
    st7920_init();
    st7920_graphics_mode();
    avr_uart_init(19200, 8, 1, 'N');
    delay_init();
    encoder_init();

    outputs_init();
    buzzer_seq_init();
    sensor_init();
    process_init(&g_state);
    cfg_load_global(&g_state);
    at_cmd_init();
    s_prev_phase = PH_IDLE;
    s_prev_atune = ATUNE_IDLE;

    ptc_off();
    fan_off();

    avr_uart_transmit_pstr(PSTR("\r\nHP\r\n"));

    sensor_tick(&g_state.sensor);
    ui_router_init(&g_state);

    {
        uint16_t t_sensor = delay_ms();

        for (;;) {
            ui_router_refresh(&g_state);

            {
                int8_t enc = encoder_poll();
                if (enc > 0)
                    ui_router_on_event(&g_state, EVT_ENCODER_NEXT);
                else if (enc < 0)
                    ui_router_on_event(&g_state, EVT_ENCODER_PREV);
            }

            if (encoder_button_pressed())
                ui_router_on_event(&g_state, EVT_PRESS);

            at_cmd_tick(&g_state);

            {
                uint16_t now = delay_ms();
                if ((uint16_t)(now - t_sensor) >= TEMP_PERIOD_MS) {
                    t_sensor = now;

                    sensor_tick(&g_state.sensor);
                    pid_notify_sample();

                    if (pid_atune_active(&g_state))
                        pid_atune_on_sample(&g_state);

                    if (safety_apply_limit(&g_state)) {
                        process_fault(&g_state);
                        g_state.telem_dirty = 1u;
                    }

                    /* Sesión USB: un $HP por muestra (autotune lo enriquece). */
                    if (device_session_is_usb(&g_state)
                        || g_state.atune_phase != s_prev_atune)
                        g_state.telem_dirty = 1u;
                    telemetry_tick(&g_state);
                    ui_router_on_sensor_update(&g_state);

                    if (g_state.phase == PH_DONE && s_prev_phase != PH_DONE)
                        buzzer_seq_beep_cat(BEEP_READY, 2);
                    /* Al salir de un ciclo (END/ERR/IDLE) el sensor ya no marca fase ni pie. */
                    if (g_state.phase != s_prev_phase)
                        g_state.row_dirty = HOME_DIRTY_ALL;

                    s_prev_phase = g_state.phase;
                    s_prev_atune = g_state.atune_phase;
                }
            }

            process_tick(&g_state);
            if (g_state.telem_dirty)
                telemetry_tick(&g_state);
            if (!pid_atune_active(&g_state))
                at_cmd_set_stream(&g_state, 0);
            buzzer_seq_tick();
        }
    }
}

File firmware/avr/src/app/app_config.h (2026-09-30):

#ifndef APP_CONFIG_H
#define APP_CONFIG_H

#include <stdint.h>

/* Safety / consignas (también en EEPROM v8)
 * temp_min_c: piso de toda consigna y T a la que para el aire (50–100 °C).
 * temp_max_c: corte de seguridad; si T lo alcanza → PTC OFF, FAULT, ERROR:7
 * (40–260 °C, AT+CFG=S). Un escalón nunca pide más que temp_cmd_hi_c(). */
#define TEMP_MIN_C_DEFAULT     50u   /* piso de consigna y OFF del aire */
#define TEMP_MAX_C_DEFAULT     210u  /* corte de seguridad; por encima del techo de consigna */
#define TEMP_MIN_C_LO          50u   /* mínimo que admite temp_min_c */
#define TEMP_MIN_C_HI          100u  /* máximo que admite temp_min_c */
#define TEMP_MAX_C_LO          40u   /* mínimo que admite el corte */
#define TEMP_MAX_C_HI          260u  /* máximo que admite el corte */
/* Techo de consigna (proceso). El corte temp_max_c queda por encima. */
#define TEMP_SET_CEILING_C     250u

/* Máximo °C que puede pedir un escalón: el menor entre el corte y el techo. */
static inline uint16_t temp_cmd_hi_c(uint16_t temp_max_c)
{
    return (temp_max_c < TEMP_SET_CEILING_C) ? temp_max_c : TEMP_SET_CEILING_C;
}
/* PH_RUN: duty alto, T bajo la banda y pendiente ~0 durante este tiempo → stall.
 * Solo cuenta con sensor válido, duty ≥ RUN_STALL_DUTY_PCT y T fuera de ±BN;
 * al cumplirse RUN_STALL_S compara la subida total con SLOPE × S. */
#define RUN_STALL_S            180u  /* ventana (s) antes de declarar estancado */
#define RUN_STALL_DUTY_PCT     95u   /* duty mínimo (%) para contar ese tiempo */
#define RUN_STALL_SLOPE_X10    2     /* |dT| ≤ 0,2 °C/s cuenta como plano */
#define TEMP_PERIOD_MS         1000u /* periodo de lectura PT100 y del PI (ms) */
#define RREF_OHM               430.0f /* Rref del MAX31865 para el PT100 (Ω) */

/* Compat: límites de consignas usan estado temp_min/max en runtime */
#define TEMP_MIN_SET_C         TEMP_MIN_C_LO /* alias del piso de consigna */
#define TEMP_MAX_SET_C         TEMP_MAX_C_HI /* alias del techo absoluto */
#define TEMP_LIMIT_C           TEMP_MAX_C_DEFAULT /* alias del corte default (°C) */
#define TEMP_LIMIT_X10         ((int16_t)(TEMP_MAX_C_DEFAULT * 10)) /* corte ×10 */

/* Texto LCD: buffers de línea (LINE_LEN + '\0') y filas marcadas en row_dirty. */
#define LINE_LEN          21u  /* caracteres útiles de una línea de texto */
#define ROW_COUNT         4u   /* filas del layout de texto */
#define ROW_ALL           0x0Fu /* máscara: las 4 filas sucias */

/* Buzzer: CONFIRM usa el pulso corto; READY (≥ 3 pulsos) y ALARM el largo. */
#define BEEP_ON_MS        30u  /* pulso corto ON (confirmación) */
#define BEEP_OFF_MS       60u  /* silencio entre pulsos cortos */
#define BEEP_ALERT_ON_MS  50u  /* pulso largo ON (listo / alarma) */
#define BEEP_ALERT_OFF_MS 80u  /* silencio entre pulsos largos */

/* Salidas físicas: PTC1/PTC2 por MOC3021 + BT136; ventilador de enfriamiento. */
#define OUT_PTC1          0u   /* índice de la resistencia 1 en out_state[] */
#define OUT_PTC2          1u   /* índice de la resistencia 2 */
#define OUT_FAN           2u   /* índice del ventilador */
#define OUTPUT_COUNT      3u   /* tamaño de out_state[] */

/* HOME: Heat | Settings. USB solo AT. */
#define HOME_COUNT         2u  /* casillas laterales */
#define HOME_IDX_HEAT      0u  /* casilla Heat */
#define HOME_IDX_SETTINGS  1u  /* casilla Settings */
#define HOME_PAGE_MENU     0u  /* el encoder cambia de casilla */
#define HOME_PAGE_SETTINGS 1u  /* lista Ajustes embebida (foco en filas) */

/* Zonas de Home en row_dirty: solo se redibuja lo marcado. */
#define HOME_DIRTY_SIDE    0x01u /* redibujar las casillas laterales */
#define HOME_DIRTY_TEMP    0x02u /* redibujar la temperatura */
#define HOME_DIRTY_BODY    0x04u /* redibujar fase, rampa y reloj */
#define HOME_DIRTY_FOOT    0x08u /* redibujar el pie RUN/STOP/EXIT */
#define HOME_DIRTY_ALL     0x0Fu /* las cuatro zonas de Home */

#define SET_PAGE_MAIN     0u   /* única página de Ajustes */
/* Ajustes embebidos: R1..R4 + retraso (+ pie Salir). Aire solo AT. */
#define SETTINGS_COUNT    5u   /* filas: R1..R4 + DLY */
#define SET_IDX_RAMP0     0u   /* fila R1 */
#define SET_IDX_RAMP1     1u   /* fila R2 */
#define SET_IDX_RAMP2     2u   /* fila R3 */
#define SET_IDX_RAMP3     3u   /* fila R4 */
#define SET_IDX_DELAY     4u   /* fila del retraso DLY */
#define SET_VIS_ROWS      4u   /* 5 opciones: la lista se desplaza en DLY/EXIT */
#define SET_HDR_H         11u  /* 2 px + glifo 7 + 2 px; "SETUP" invertido */
#define SET_HDR_GAP       2u   /* aire bajo el header, fuera de la banda invertida */
#define SET_ROW_Y0        (SET_HDR_H + SET_HDR_GAP) /* 13: Y de la primera fila */
#define SET_ROW_H         9u   /* 1 px + glifo 7 + 1 px, todo en el inverso */
#define SET_ROW_PAD       1u   /* separación entre opciones, fuera del inverso */
#define SET_ROW_STEP      (SET_ROW_H + SET_ROW_PAD) /* 10; 13+3×10+9 = 52 < pie 54 */
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

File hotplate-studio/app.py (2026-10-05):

#!/usr/bin/env python3
"""Punto de entrada: `python hotplate-studio/app.py`."""

from __future__ import annotations

import sys
from pathlib import Path

# Los módulos viven sueltos en esta carpeta: se añaden al path para poder importarlos.
sys.path.insert(0, str(Path(__file__).resolve().parent))

from window import MainWindow


def main() -> None:
    # En el binario (--macos-app-mode=gui) no hay consola: si el arranque falla,
    # el motivo queda en hotplate-studio.log junto al ejecutable.
    try:
        MainWindow().mainloop()
    except Exception:
        import traceback

        here = Path(sys.executable).resolve().parent if getattr(sys, "frozen", False) else Path(__file__).resolve().parent
        log = here / "hotplate-studio.log"
        log.write_text(traceback.format_exc(), encoding="utf-8")
        traceback.print_exc()
        raise


if __name__ == "__main__":
    main()

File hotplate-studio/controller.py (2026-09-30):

"""Orquestación: serie, comandos AT, dispatch RX → estado/vistas."""

from __future__ import annotations

import csv
import queue
import threading
import time
from typing import TYPE_CHECKING, Callable, Optional

from tkinter import filedialog, messagebox

import protocol as proto
import ramps_store
import theme as ui_theme
import tune_store
from constants import POLL_MS
from serial_link import SerialLink
from state import SessionState

if TYPE_CHECKING:
    import tkinter as tk

    from views.appearance_view import AppearanceView
    from views.connection_view import ConnectionView
    from views.heat_view import HeatView
    from views.settings_view import SettingsView
    from views.status_bar import HeaderBar, StatusBar
    from views.tune_view import TuneView


class AppController:
    def __init__(self, root: "tk.Tk", state: SessionState) -> None:
        self.root = root
        self.state = state
        self._rx: queue.Queue = queue.Queue()
        self.link = SerialLink(self._rx)
        self._stat_job: Optional[str] = None

        # Vistas (inyectadas tras construir la ventana)
        self.conn: ConnectionView
        self.heat: HeatView
        self.settings: SettingsView
        self.tune: TuneView
        self.status_bar: StatusBar
        self.header: HeaderBar
        self.appearance: AppearanceView

    def bind_views(
        self,
        conn: "ConnectionView",
        heat: "HeatView",
        settings: "SettingsView",
        tune: "TuneView",
        status_bar: "StatusBar",
        appearance: "AppearanceView",
        header: "HeaderBar",
    ) -> None:
        self.conn = conn
        self.heat = heat
        self.settings = settings
        self.tune = tune
        self.status_bar = status_bar
        self.header = header
        self.appearance = appearance
        ramps_store.load_ramps(
            lambda i, v: self.heat.ramp_active[i].set(v),
            lambda i, v: self.heat.ramp_temp[i].set(v),
            lambda i, v: self.heat.ramp_hold[i].set(v),
        )
        self.heat.ramp_active[0].set(True)
        self.heat.refresh_objetivo()
        self.refresh_chrome()
        self.root.after(POLL_MS, self._poll_rx)

    def apply_theme(self) -> None:
        ui_theme.apply_ttk(self.root)
        self.conn.apply_theme()
        self.heat.apply_theme()
        self.tune.apply_theme()
        self.settings.apply_theme()
        self.appearance.apply_theme()
        self.status_bar.apply_theme()

    def save_theme(self) -> None:
        partial = self.appearance.collect_theme()
        ui_theme.save(partial)
        self.apply_theme()
        messagebox.showinfo(
            "Tema",
            "Apariencia aplicada y guardada (ui_theme.json).",
        )

    def reset_theme(self) -> None:
        ui_theme.reset_defaults()
        self.appearance.reload_theme_vars()
        self.apply_theme()
        messagebox.showinfo("Tema", "Tema restaurado a los valores por defecto.")

    # ---- chrome / sesión ----

    def refresh_chrome(self) -> None:
        st = self.state
        connected = self.link.connected
        self.status_bar.update(
            connected, st.device_online, st.conn_port, st.usb_mode
        )
        self.header.update(st.device_online, st.usb_mode)
        self.heat.status.set_stream_mode(st.usb_mode)
        self.tune.status.set_stream_mode(st.usb_mode)
        self.conn.refresh_session_ui(connected, st.device_online, st.usb_mode)

    def toggle_conn(self) -> None:
        if self.link.connected:
            self.disconnect()
        else:
            self.connect()

    def connect(self) -> None:
        port = self.conn.selected_port()
        if not port:
            messagebox.showerror("Puerto", "Elige un puerto serie")
            return
        try:
            self.link.open(port)
        except Exception as exc:
            messagebox.showerror("Conexión", str(exc))
            return
        self.state.conn_port = port
        self.state.device_online = False
        self.state.usb_mode = False
        self._cancel_stat()
        self.refresh_chrome()
        self.conn.log_line(
            "--",
            "puerto abierto — el saludo HP solo sale al encender; preguntando con AT…",
        )
        self._probe_boot()

    def disconnect(self) -> None:
        self._cancel_stat()
        self.link.close()
        self.state.reset_link()
        self.refresh_chrome()

    def _probe_boot(self) -> None:
        """El equipo ya encendido no repite HP. AT → OK lo da por en línea."""

        def work() -> None:
            try:
                result = self.link.send(proto.cmd_at())
            except Exception as exc:
                msg = str(exc)
                self.root.after(0, lambda m=msg: self._probe_boot_fail(m))
                return
            if result.kind == "OK":
                self.root.after(0, self._probe_boot_ok)

        self.conn.log_line("TX", proto.cmd_at())
        threading.Thread(target=work, daemon=True).start()

    def _probe_boot_ok(self) -> None:
        if not self.link.connected or self.state.device_online:
            return
        self.conn.log_line("RX", "OK")
        self.conn.log_line("--", "equipo en marcha (AT → OK)")
        self.on_device_online()

    def _probe_boot_fail(self, msg: str) -> None:
        if not self.link.connected or self.state.device_online:
            return
        self.conn.log_line(
            "!!",
            f"{msg}. Sin respuesta: el firmware grabado y Studio tienen que ir los dos a 19200.",
        )

    def on_device_online(self) -> None:
        if self.state.device_online:
            return
        self.state.device_online = True
        self.conn.log_line("--", "equipo en línea")
        self.refresh_chrome()
        self.toggle_stat_poll()

    def toggle_mode(self) -> None:
        if self.state.usb_mode:
            self.send(proto.cmd_mode(0), after_ok=self._on_manual_ok)
        else:
            self.send(proto.cmd_mode(1), after_ok=self._on_usb_enter)

    def _on_manual_ok(self) -> None:
        self._set_usb_mode(False)

    def _on_usb_enter(self) -> None:
        self._set_usb_mode(True)
        self.read_ramps()
        self.read_cfg()

    def _set_usb_mode(self, on: bool) -> None:
        """En USB el equipo empuja $HP a 1 Hz; en Manual vuelve el sondeo."""
        self.state.usb_mode = on
        self.refresh_chrome()
        self.toggle_stat_poll()

    def on_close(self) -> None:
        self._cancel_stat()
        self.link.close()
        self.root.destroy()

    # ---- comandos ----
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

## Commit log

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2026-03-07 feat: enhance README and add non-blocking animation strategy
    - Updated README.md to include details on non-blocking animations for the ST7920 LCD, including new API functions and documentation links.
    - Added new documentation file for non-blocking animation strategies.
    - Introduced .vscode/tasks.json for build and clean tasks.
    - Added multiple animated icons (automation, copy, normal distribution histogram, notes, plot, temperature) with optimized frame data.
2026-03-08 feat: add MAX31865 sensor support and improve Makefile for debug builds
    - Introduced MAX31865 library for PT100/P1000 RTD sensor, including initialization, reading, and temperature conversion functions.
    - Updated Makefile to support both normal and debug builds, allowing for separate compilation of main and debug source files.
    - Modified board_pins.h to reflect changes in chip select pins for LCD and MAX31865.
    - Enhanced main.c to integrate MAX31865 readings and display temperature on ST7920 LCD.
    - Added new functions for buzzer and PTC control in ports library.
    [board_pins.h, main.c]
2026-03-08 refactor: update README and documentation for SPI and non-blocking timing
    - Enhanced README.md with detailed descriptions of SPI hardware and software configurations for the ST7920 and MAX31865.
    - Added a new documentation file for non-blocking timing strategies, providing examples and usage patterns.
    - Updated board_pins.h to clarify pin assignments for SPI hardware and software.
    - Improved documentation links across various files for better navigation and understanding of the system architecture.
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2026-09-27 refactor: enhance Makefile, add new services, and update documentation for improved functionality
    - Updated the Makefile to include new source files for proto handling and ensure atomic writes during object compilation.
    - Added new services for protocol error handling and token management to streamline UART communication.
    - Enhanced documentation to clarify the architecture and product features, including updates to program flows and USB automation.
    - Refined UI components and settings view to improve user experience and accessibility of configuration options.
    - Removed unused tokens and streamlined internationalization keys for better code maintainability.
    [app_config.h, at_cmd.c]
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2026-09-27 feat: add AT command for reading ramp steps and update documentation
    - Implemented the `AT+CFG=R?` command to read and emit ramp step configurations.
    - Enhanced telemetry to support the new `$R` response format, providing detailed ramp step information.
    - Updated documentation to include the new command and its usage, clarifying the structure of the ramp data.
    - Added tests to verify the correct functionality of the new command and response format.
    [at_cmd.c, telemetry.c]
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2026-09-28 chore: promote monorepo root (firmware, host-ui, hardware, mechanical)
    Move git root from firmware/avr/ to the project root so the GitHub
    repo matches the full product tree. Preserve history via renames into
    firmware/avr/. Datasheets live under hardware/datasheets/.
    [.stl, Case.3mf, Hotplate-Tapa-trasera.3mf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]
2026-09-28 chore: drop KiCad lock/cache binaries from tracking
    [.stl]
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2026-09-28 refactor: enhance heat control and predictive PID simulation
    - Updated AGENTS.md to clarify the HEAT and PID_TUNE commands, emphasizing the predictive PI control and ramp configurations.
    - Introduced a new Python script for offline simulation of predictive PID behavior, allowing for better analysis of temperature control dynamics.
    - Added a new CSV file containing adjusted hotplate tuning data for improved testing and validation of the heating process.
    - Removed the outdated hotplate tuning trace CSV file to streamline data management.
    - Enhanced the Makefile to include new test targets for the predictive PID functionality, ensuring comprehensive testing coverage.
    - Revised documentation acr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
    [hotplate_tune_trace.csv, hotplate_tune_trace_ajustado.csv]
2026-09-28 refactor: improve heat state management in AppController
    - Added heat_seen_active state to track the activation of heat during recording.
    - Updated stop and start recording methods to reset heat_seen_active appropriately.
    - Ensured heat_seen_active is cleared in various scenarios to maintain accurate state management.
    [controller.py, state.py]
2026-09-28 feat: add hotplate tuning and heat trace data files
    - Introduced new CSV files for hotplate tuning and heat trace data, providing detailed temperature and power metrics for analysis.
    - Added corresponding PNG charts for visual representation of the tuning and heating processes, enhancing data accessibility and interpretation.
    [hotplate_heat_trace.csv, hotplate_tune_trace_ajustado.csv]
2026-09-29 feat: add new heat trace data and enhance PID control features
    - Introduced a new CSV file for hotplate heat trace data, capturing detailed temperature and power metrics.
    - Added a PNG file for visual representation of the heat trace data.
    - Updated product features documentation to reflect changes in PID control logic, emphasizing the predictive PI approach and ramp configurations.
    - Enhanced program flow documentation to clarify the new phases and control mechanisms in the heating process.
    [hotplate_heat_trace-2.csv]
2026-09-29 feat: update documentation and add new license file
    - Updated AGENTS.md to reflect the latest product features and critical rules, including changes to the UI and core functionalities.
    - Added LICENSE file detailing the open-source licensing terms for software and hardware components.
    - Revised README.md to enhance clarity on product features and repository structure.
    - Introduced new heat trace data files and updated existing documentation to improve accessibility and understanding of the heating process.
    - Enhanced the Makefile to exclude specific font files from the build process, optimizing the firmware size.
    [hotplate_heat_trace-3.csv, hotplate_heat_trace-4.csv]
2026-09-29 feat: enhance documentation and update firmware features
    - Updated AGENTS.md to clarify HEAT and PID_TUNE commands, including detailed descriptions of delays and preheating phases.
    - Revised README.md to improve explanations of scheduled start times and the overall heating process.
    - Added new CSV files for hotplate tuning and heat trace data, providing comprehensive metrics for analysis.
    - Introduced new PNG files for visual representation of heat trace data, enhancing data accessibility.
    - Enhanced Makefile to optimize the build process by excluding unnecessary font files.
    - Updated various documentation files to reflect changes in features, UI elements, and command structures, ensuring cl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
    [hotplate_tune_trace-2.csv]
2026-09-29 feat: update documentation and enhance USB session features
    - Added a new document detailing future improvements and errata in mejoras_futuras.md.
    - Updated AGENTS.md and README.md to include references to mejoras_futuras.md and clarify the USB session's telemetry structure.
    - Enhanced the Makefile to support new UI screen generation for improved documentation visuals.
    - Revised various documentation files to reflect changes in the USB communication protocol and session management, ensuring clarity for developers.
    - Introduced new images for the HotPanel UI to enhance visual documentation and user understanding.
    [app_config.h, chart.py, constants.py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]
2026-09-29 fix: update font handling and documentation for temperature display
    - Revised AGENTS.md and architecture.md to reflect changes in font usage, specifically the introduction of FONT_8X12 for temperature display.
    - Updated Makefile to include FONT_8X12 in the build process, ensuring proper linkage for temperature representation.
    - Enhanced documentation in feature_budget.md and ui_style_guide.md to clarify the new font specifications and their implications for UI design.
    - Added new CSV files for hotplate heat events and traces, providing detailed metrics for temperature and power analysis.
    - Updated various source files to utilize FONT_8X12 for temperature readings, improving visual clarity in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
    [hotplate_heat_eventos-1.csv, hotplate_heat_trace-1.csv]
2026-09-30 feat: enhance documentation and add new data files for heat analysis
    - Updated README.md to reflect changes in future improvements and errata, clarifying the latest findings in thermal performance.
    - Revised various documentation files, including mejoras_futuras.md, to include results from recent thermal tests and algorithm improvements.
    - Added new CSV files for hotplate tuning events and traces, providing detailed metrics for temperature and power analysis.
    - Introduced a new PNG file for visual representation of tuning data, enhancing accessibility for users.
    - Updated Makefile to include new test targets for real trace regression, ensuring comprehensive testing coverage for the heating p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
    [hotplate_tune_eventos-3(kp78-ki6).csv, hotplate_tune_trace-3(kp78-ki6).csv]
2026-09-30 fix: update feature budget documentation and improve main application error handling
    - Revised feature_budget.md to reflect the latest program size measurements and memory usage, ensuring accurate tracking of firmware resources.
    - Enhanced main.c to mark the state as dirty when transitioning phases, improving UI responsiveness.
    - Updated app.py to include error logging for GUI startup failures, providing better diagnostics for users in macOS app mode.
    [app.py, main.c]
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2026-10-05 chore: clean up project by removing obsolete files and updating .gitignore
    - Deleted outdated heat simulation script (heat_predictive_sim.py) and various CSV and PNG files related to hotplate tuning and heat traces.
    - Updated .gitignore to exclude temporary files (*.temp) to prevent clutter in the repository.
    [hotplate_heat_trace-2.csv, hotplate_heat_trace-3.csv, hotplate_heat_trace-4.csv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]
2026-10-07 feat: update landing page media and enhance hero section functionality
    - Replaced the hero image and updated its attributes in landing.json for improved visual representation.
    - Modified site.json to enhance the Open Graph image description for better social media sharing.
    - Added new media assets including images and videos for the landing page and tutorials.
    - Introduced a new HeroScene component to provide an interactive experience in the hero section.
    - Implemented animations for the hero elements in index.css to enhance user engagement.
    - Updated i18n messages to include new terms related to the hero section and its features.
    - Created a build script for generating tutorial videos with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
2026-10-09 feat: integrate Google Tag Manager and gtag.js for enhanced tracking
    - Replaced the existing Google Tag Manager ID in site.json with a new gtag.js ID for improved analytics tracking.
    - Added functions in vite-plugin-landing.ts to generate gtag.js script tags, ensuring proper integration of Google Analytics on the landing page.
